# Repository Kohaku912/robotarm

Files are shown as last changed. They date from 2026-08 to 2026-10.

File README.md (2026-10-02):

# 6軸 カメラグリッパ・ロボットアーム（パラメトリック設計）

> **FreeCAD + Python による完全パラメトリックな 6 軸アーム。** 1 つのパラメータ表から
> CAD・STL・URDF・2D 図面を生成し、6 種類の自動検証（干渉・可到達範囲・印刷サイズ・
> 締結形状・サーボ駆動・自己干渉）をすべてパスさせています。







**English summary** — A fully parametric 6-DOF camera-gripper arm designed in FreeCAD from a
single parameter table, which then generates STL meshes, a URDF model, and 2D drawings.
An automated validation suite checks print-bed size, fastener features, forward-kinematics
reach, collision, servo drive torque, and self-collision — **6/6 passing**.

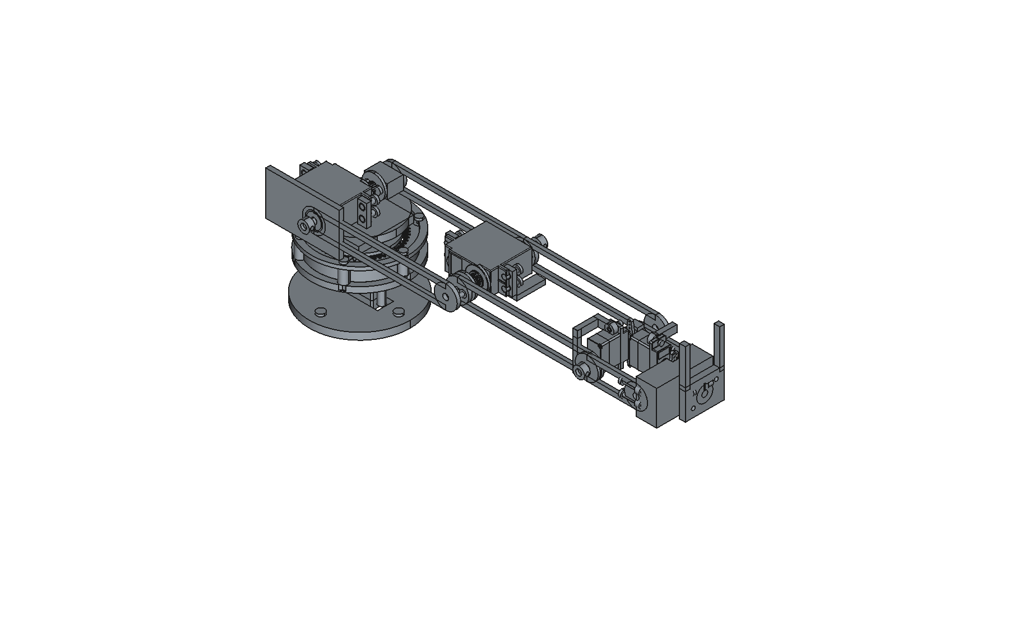
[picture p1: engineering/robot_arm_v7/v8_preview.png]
アーム外観


---

## 仕様

| 項目 | 値 |
|---|-----|
| 自由度 | 6 軸（J1 ヨー / J2 肩 / J3 肘 / J4 手首ピッチ / J5 ロール / J6 ヨー）+ グリッパ + カメラチルト |
| 到達距離（目安） | ~350 mm（上腕 140 + 前腕 120 + 手首 ~70） |
| ペイロード | 先端 100 g |
| サーボ | MG996R ×2（J1/J2）、MG90S ×6（J3–J6・グリッパ・カメラチルト） |
| 軸受 | F695ZZ ×5、F685ZZ ×5（フランジ軸受で径方向荷重を受ける） |
| 印刷制約 | 1 パーツ ≤180 mm（実測最大 129.92 mm） |
| 締結 | **接着禁止** — ねじ・圧入・軸嵌合のみ |

設計根拠は [`docs/design_notes.md`](docs/design_notes.md)、2D 図面は [`docs/2d/`](docs/2d/) を参照。

## 設計方針

実機（OmArm / Omartronics 系）のパターンに合わせ、
**サーボ片側＋対向フランジ軸受＋ホーン締結** を全関節で統一しています。

1. **固定側** — サーボポケット（公開寸法のタブ穴で位置決め）
2. **駆動側** — 円形ホーンをリンクにねじ止め
3. **反対側** — F695 / F685 フランジ軸受座 + Ø5 軸
4. ケーブル通し穴を確保し、分割リンクはダボ + M3 インサートで結合

サーボ出力軸に曲げモーメントを入れない構成にすることで、
MG90S のような小型サーボでも関節を成立させています。

---

## 生成物

`params.py` を唯一の真実源として、FreeCAD 経由で以下を再生成できます。

| 出力 | 内容 |
|---|---|
| `export/stl/` | 印刷用 STL **20 点**（ベース板〜フィンガ） |
| `export/fcstd/RobotArm.FCStd` | FreeCAD アセンブリ |
| `export/vendor/*.step` | サーボ／軸受／ホーンの参照モデル |
| `urdf/robot_arm.urdf` + `urdf/meshes/` | シミュレーション用 URDF |
| `docs/2d/*.svg` | 2D プロファイル **11 点** |

## 生成手順（FreeCAD）

FreeCAD の Python コンソールで、リポジトリの `generate_arm.py` を実行します。

```python
exec(open("generate_arm.py", encoding="utf-8").read())
```

> 絶対パスで実行する場合は、クローンしたディレクトリの `generate_arm.py` を指定してください。

SVG のみ再出力する場合:

```bash
python cad/export_svg.py
```

寸法変更は [`params.py`](params.py) を編集して再生成するだけです。

---

## 検証結果

```bash
py -3.11 tests/run_validation.py
```

結果は `export/validation_report.json` に出力されます。**全 6 項目パス**（`"ok": true`）。

| 検証項目 | 内容 | 結果 |
|---|---|---|
| `print_size` | 全 STL が印刷ベッド内（最大 129.92 mm） | ✅ |
| `fastener_features` | ねじ穴・インサート座の形状検証 | ✅ |
| `fk_reach` | 順運動学による到達距離 | ✅ |
| `collision` | パーツ間干渉チェック | ✅ |
| `servo_drive` | サーボ駆動トルクの余裕 | ✅ |
| `self_collision_flag` | 自己干渉の判定 | ✅ |

---

## 物理シミュレーション

### PyBullet（GUI 操作デモ）

Python **3.10–3.12** が必要です。

```bash
py -3.11 -m pip install pybullet
py -3.11 sim/pybullet_arm.py
```

または `sim/run_gui.bat`。スライダーで J1–J6・グリッパ・カメラチルトを動かすと、
重力下でアーム全体が追従します。ヘッドレス確認:

```bash
py -3.11 sim/pybullet_arm.py --direct
```

### numpy フォールバック

PyBullet が使えない環境向け。PD サーボ追従＋重力トルクの簡易物理:

```bash
py -3.11 -m pip install numpy matplotlib
py -3.11 sim/numpy_physics_arm.py
# または
py -3.11 sim/numpy_physics_arm.py --no-plot
```

---

## 組立順（概略）

1. ベース板＋カラムに MG996R と F695ZZ → タレット下面軸受・ホーン結合
2. タレット U 頬に F695ZZ ×2 → 肩 MG996R → ホーン／アイドラを上腕へ
3. 上腕分割結合 → 肘 MG90S + F695ZZ
4. 前腕 → 手首ピッチ／ロール／ヨー（F685ZZ）
5. グリッパ → カメラチルト（60×8 基板、Ø6 レンズ逃げ）

締結の詳細は [`bom.md`](bom.md) を参照。

---

## リポジトリ構成

```
params.py            # 寸法パラメータ（唯一の真実源）
generate_arm.py      # FreeCAD 生成スクリプト
cad/                 # 2D スケッチ・押し出し定義
sim/                 # PyBullet / numpy シミュレーション
tests/               # 自動検証スイート
urdf/                # URDF + メッシュ
export/              # 生成物（STL / FCStd / STEP / 検証レポート）
docs/                # 設計ノート・2D 図面
engineering/         # 設計検討の履歴（プレビュー画像を含む）
bom.md               # 部品表・締結仕様
```

## ライセンス

© 2026 Kohaku912. All rights reserved.

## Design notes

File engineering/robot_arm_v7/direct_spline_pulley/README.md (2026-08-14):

# MG996Rホーンレス直結16Tプーリー試作

支給された `MG996R_SERVO.step` の出力スプラインB-repを雌型として使用した、J2用3GT 16T・幅9 mmの試作部品。ホーンは使用せず、スプラインでトルクを伝え、中央M3ねじで軸方向を保持する。

## 重要

- 状態は `PROTOTYPE_NOT_LOAD_APPROVED`。主設計の支持入力軸とF685ZZ×2を省略するため、約120.7 Nのベルト接線力と張力がサーボ出力軸受へ戻る。
- クーポンの角欠き側が0.05 mm、中央が0.10 mm、反対端が0.15 mm。試験は反対端の0.15、中央0.10、角欠き側0.05 mmの順で、電源を切ったサーボへ手で試す。工具で押し込まない。
- 中央ねじはM3×8またはM3×10、頭径6 mm・高さ2 mmを想定。実サーボの中央雌ねじがM3であること、底付きしないことを実測する。
- 0.10 mm版を標準STLにした。緩い場合でも接着剤で補修せず、クリアランス値を変更して再生成する。

## 印刷条件

- Fiberon PA12-CF10、乾燥条件を材料仕様に従って記録
- 軸方向Z、0.15 mm層、8周、スプライン周囲100%相当
- 積層後にバリだけ除去し、スプライン歯面をドリルやリーマで加工しない

## 合格手順

1. クーポンが手圧で奥まで入り、逆さにして自然落下せず、抜去後にサーボ歯面を傷つけない。
2. 中央ねじを低トルクで締め、プーリー端面の振れを測る。
3. 無負荷で低速往復し、割れ、偏心、異音がない。
4. ベルトを掛ける前に30秒保持試験を行う。
5. ベルト試験では軸受温度、ガタ、歯飛びを確認する。合格するまでロボットアームへ採用しない。

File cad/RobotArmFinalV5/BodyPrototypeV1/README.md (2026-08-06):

# Robot Arm Body Prototype V1

5軸ロボットアーム本体の印刷データです。公差クーポンは含みません。

## 確定公差
- F695ZZ座: 13.05 mm
- M5密着穴: 5.00 mm
- M5通し穴: 5.30 mm
- J1歯車中心距離: 54.55 mm
- J4歯車中心距離: 19.35 mm

`BODY_PLATE_01.stl`から順に印刷できます。各部品は4 mm以上の外接間隔で完全に分離され、接続線・外周フレーム・クーポンはありません。

最初は無通電で全軸を手回しし、F695ZZ外輪押さえ、M5軸カラー、歯車噛み合いを確認してください。

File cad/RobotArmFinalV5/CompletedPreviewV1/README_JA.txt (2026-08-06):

Robot Arm Completed Preview V1

Printed body: BodyPrototypeV1 source geometry
MG90S: TowerPro official nominal 22.8 x 12.2 x 28.5 mm, 13.4 g
MG996R: TowerPro official nominal 40.7 x 19.7 x 42.9 mm, 55 g
F695ZZ: NSK 5 x 13 x 4 mm, flange 15 x 1 mm
Straight home pose. Minor clone/cap/label/cable variations may differ.

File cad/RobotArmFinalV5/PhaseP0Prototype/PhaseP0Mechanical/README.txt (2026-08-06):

V5.7-P0 mechanical package. J1 print plates use separated solids with no connector lines. Conservative envelopes are broad-phase only.

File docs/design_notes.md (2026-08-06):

# Realistic redesign notes — sources and mechanical rationale

## Reference projects

| Project | Reach | Payload | Actuators | Takeaway |
|---|---|---|---|---|
| OmArm Zero | ~303 mm | ~141 g | 3× MG996R + 3× SG90 | With only 2× MG996R, keep reach ~350 mm and short distal links |
| Omartronics 6-DOF | hobby | light | MG996R base/shoulder/elbow | Base servo + bearing under turret; U-yoke shoulder |
| Typical servo arm | — | — | horn + opposite bearing | Load path never through servo case alone |
| Thor | 625 mm | 750 g | steppers + belts | Structural inspiration only; not used (wrong actuators) |

## Joint pattern (applied to every revolute joint)

1. Servo body pocket with datasheet tab-hole spacing
2. Circular horn bolted to the driven link
3. Opposite cheek: flanged bearing seat + Ø5 shaft through bearing ID
4. Cable pass-through with rounded entry
5. Soft mechanical stops near ±90° (servo 180° class)

## Bearing allocation (stock exact)

- F695ZZ ×5: J1×2, J2×2, J3×1
- F685ZZ ×5: J4×2, J5×2, J6×1

## Link lengths (axis to axis)

- Upper arm: 140 mm (split 70+70 for 180 mm bed)
- Forearm: 120 mm (split 60+60)
- Wrist stack: ~70 mm
- Approx reach (J1 axis to wrist flange): ~350 mm

## Hardware dimensions (rebuilt from published specs, not copied CAD)

- MG996R: body ~40.7×19.7, tab length ~54.5, hole pitch ~49.5×10
- MG90S: body ~22.8×12.2×28.5, tab hole pitch ~28
- F695ZZ: 5×13×4, flange Ø15
- F685ZZ: 5×11×5, flange Ø12.5

## CAD method

1. Draw 2D profiles (`docs/2d/*.svg` + sketch point loops)
2. Extrude / pocket via `cad/sketch_pad.py` (Sketch→Pad equivalent)
3. Fit-check against `vendor/` solids
4. Export STL + URDF; drive with PyBullet position-controlled joints

## Torque note

MG996R ~10 kg·cm. Tip 100 g at 350 mm ≈ 3.5 kg·cm from payload alone; self-weight adds more.
Shoulder (J2) is the bottleneck. Elbow on MG90S requires the shorter forearm.

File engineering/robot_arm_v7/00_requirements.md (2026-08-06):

# ROBOT ARM V7 設計入力

状態: `PRE-CAD COMPLETE / CAD AUTHORIZED`

## 性能要求

| ID | 項目 | 設計値 |
|---|---|---:|
| REQ-01 | 先端ペイロード | 50 g |
| REQ-02 | 公称最大リーチ | 288 mm |
| REQ-03 | 水平保持 | 30 s、デューティ20% |
| REQ-04 | 最大関節速度 | 60 deg/s |
| REQ-05 | 最大関節加速度 | 120 deg/s^2 |
| REQ-06 | 急停止減速度 | 600 deg/s^2 |
| REQ-07 | サーボ電源 | 4.8 V nominal |
| REQ-08 | 構造安全率 | 2.0 |
| REQ-09 | 軸・ねじ安全率 | 2.0 |
| REQ-10 | 軸受静定格安全率 | 1.5 |
| REQ-11 | 接合方式 | ねじ、インサート、クランプ、軸、軸受、スプライン、圧入のみ |
| REQ-12 | 禁止 | 魔法の固定、CAD拘束だけの動力伝達、未定義接着、部品重なり |

## 材料・製造

| ID | 対象 | 指定 |
|---|---|---|
| MAT-01 | 構造部品 | Fiberon PA12-CF10、FDM、密度1.06 g/cm3 |
| MAT-02 | 遊星歯車 | PA12、FDM試作。20 degインボリュートへ更新必須 |
| MAT-03 | 軸 | 直径5 mm SUJ2相当精密シャフト |
| MAT-04 | ねじ・カラー | 鋼製市販品 |
| MAT-05 | FDM許容応力 | Z方向の湿潤引張強度42.1 MPaに対し、設計許容20 MPa |

## 未確定入力

| ID | 不足情報 | 完成判定への影響 |
|---|---|---|
| IN-01 | M3インサート | 解決: 熱圧入、外径6、全長4 mm、100個 |
| IN-02 | M4インサート | 解決: 熱圧入、外径5、全長3～8 mmを各30個 |
| IN-03 | 各ねじ長さごとの在庫数量 | 最終BOMの必要数量と現物を照合する |

ねじ数量の照合が終わるまで購入不足判定のみ`CONDITIONAL`とする。CAD設計は開始可能。

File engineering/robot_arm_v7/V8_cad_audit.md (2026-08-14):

# V8 automated CAD audit

Overall: **FAIL_NOT_COMPLETE**

Physical features: 157; arm mass excluding fixture inserts: 558.57 g.

| Check ID | Status | Evidence |
|---|---|---|
| AUD-MATERIAL-METADATA | PASS | 157 physical features covered |
| AUD-SHAPE-VALIDITY | PASS | 157 valid B-reps |
| AUD-UNCONNECTED | PASS | No physical feature lacks a ConnectionID |
| AUD-PRINTED-SINGLE-SOLID | PASS | 25 printed BOM parts are each one connected solid |
| AUD-NO-OVERLAP-AS-JOINT | PASS | No structural overlap is authorized merely by a shared ConnectionID; tolerance 0.05 mm3 |
| AUD-INVENTORY-F695 | PASS | {"installed": ["F695_J1_1", "F695_J1_2", "F695_J2_L", "F695_J2_R", "F695_J3", "F695_J4"], "owned": 5, "purchase_required": 1} |
| AUD-INVENTORY-F685 | PASS | {"installed": ["J1_PLANET_BRG_1", "J1_PLANET_BRG_2", "J1_PLANET_BRG_3", "F685_J5_A", "F685_J5_B", "F685_J2_INPUT_A", "F685_J2_INPUT_B"], "owned": 5, "purchase_required": 2} |
| AUD-INSERT-M3-SPEC | PASS | ["J1_CASE_1:OD6.0xL4.0", "J1_CASE_2:OD6.0xL4.0", "J1_CASE_3:OD6.0xL4.0", "J1_CASE_4:OD6.0xL4.0", "J1_CASE_5:OD6.0xL4.0", "J1_CASE_6:OD6.0xL4.0", "J1_OUTPUT_CLAMP:OD6.0xL4.0", "J2_SHAFT_CLAMP_L:OD6.0xL4.0", "J2_SHAFT_CLAMP_R:OD6.0xL4.0", "UA_SPACER_1_L:OD6.0xL4.0", "UA_SPACER_1_R:OD6.0xL4.0", "UA_SPACER_2_L:OD6.0xL4.0", "UA_SPACER_2_R:OD6.0xL4.0", "J5_HOUSING_INS_1_1:OD6.0xL4.0", "J5_HOUSING_INS_1_2:OD6.0xL4.0", "J5_HOUSING_INS_2_1:OD6.0xL4.0", "J5_HOUSING_INS_2_2:OD6.0xL4.0", "J5_TOOL_CLAMP:OD6.0xL4.0", "J2_BRIDGE_INS_1:OD6.0xL4.0", "J2_BRIDGE_INS_2:OD6.0xL4.0", "J2_BRIDGE_INS_3:OD6.0xL4.0", "J2_BRIDGE_INS_4:OD6.0xL4.0", "J4_HORN_1:OD6.0xL4.0", "J4_HORN_2:OD6.0xL4.0"] |
| AUD-INSERT-M4-SPEC | PASS | ["BASE_M4_1:OD5.0xL6.0", "BASE_M4_2:OD5.0xL6.0", "BASE_M4_3:OD5.0xL6.0", "BASE_M4_4:OD5.0xL6.0", "J2_SERVO_1_1:OD5.0xL4.0", "J2_SERVO_1_2:OD5.0xL4.0", "J2_SERVO_2_1:OD5.0xL4.0", "J2_SERVO_2_2:OD5.0xL4.0", "J3_SERVO_1_1:OD5.0xL4.0", "J3_SERVO_1_2:OD5.0xL4.0", "J3_SERVO_2_1:OD5.0xL4.0", "J3_SERVO_2_2:OD5.0xL4.0"] |
| AUD-FASTENER-LENGTH-ENGAGEMENT | PASS | 49 screws within inventory/purchase ranges |
| AUD-TOOL-ACCESS | PASS | 49 screws define direction, >=8 mm clearance, and assembly stage |
| AUD-SERVO-STEP-HOLE-AXIS | PASS | 14 servo fastener axes match STEP hole/slot centers within 0.05 mm |
| AUD-PHYSICAL-CONNECTION-GRAPH | FAIL | ["C-J2-HORN-COUPLER:J2_SERVO_HORN", "C-J2-HORN-COUPLER:J2_HORN_SHAFT_COUPLER", "C-J3-ACTIVE:J3_SERVO_HORN", "C-J3-ACTIVE:J3_HORN_M3_1", "C-J3-ACTIVE:J3_HORN_1"] |
| AUD-NO-MAGIC-FIXED-JOINTS | PASS | No FreeCAD constraint is credited as hardware |
| AUD-INTEGRAL-SERVO-MOUNTS | PASS | J1-J5 cradle features are fused into one-solid structural hosts; no separate mount BOM items |
| AUD-SERVO-HOST-NO-VOLUME-OVERLAP | PASS | All purchased servo cases have zero common volume with their printed hosts; seating is by ear faces |
| AUD-EXACT-SERVO-HORN-GEOMETRY | FAIL | ["J2_SERVO_HORN", "J3_SERVO_HORN"] |
| AUD-EXACT-SERVO-BODY-GEOMETRY | PASS | All five servo bodies trace to supplied STEP files |
| AUD-PURCHASED-SERVO-UNMODIFIED | PASS | Placed servo B-rep volumes equal source volumes within 0.01 mm3 |
| AUD-PITCH-LOAD-CASES-SF | PASS | [{"joint": "J2", "stall_Nm": 1.6596, "load_cases": {"static": {"demand_Nm": 0.517907, "sf": 3.2044}, "max_accel_120_deg_s2": {"demand_Nm": 0.544641, "sf": 3.0471}, "emergency_stop_600_deg_s2": {"demand_Nm": 0.65158, "sf": 2.547}}}, {"joint": "J3", "stall_Nm": 0.922, "load_cases": {"static": {"demand_Nm": 0.247761, "sf": 3.7213}, "max_accel_120_deg_s2": {"demand_Nm": 0.256204, "sf": 3.5987}, "emergency_stop_600_deg_s2": {"demand_Nm": 0.289976, "sf": 3.1796}}}, {"joint": "J4", "stall_Nm": 0.177, "load_cases": {"static": {"demand_Nm": 0.068699, "sf": 2.5765}, "max_accel_120_deg_s2": {"demand_Nm": 0.069538, "sf": 2.5454}, "emergency_stop_600_deg_s2": {"demand_Nm": 0.072896, "sf": 2.4281}}}] |
| AUD-J2-PHYSICAL-2TO1-BELT | PASS | {"part": "BELT-J2-135-3GT-90", "ratio": 2.0, "efficiency": 0.9, "pitch_mm": 3.0, "width_mm": 9.0, "length_mm": 135.0, "wrap_deg": 151.0323, "engaged_teeth": 6.7125} |
| AUD-MUJOCO-TRANSMISSION-MATCH | PASS | {"motor": "J2_MG996R_16T_32T_3GT", "gear_Nm": 1.6596, "ratio": "2.0", "efficiency": "0.90", "transmission_id": "P-J2-BELT"} |
| AUD-BELT-CAPACITY-PHYSICAL-COUPON | FAIL | 3GT printed-tooth coupon and MISUMI capacity confirmation are required before manufacture approval |
| AUD-PHYSICAL-VALIDATION | FAIL | Pending insert pull-out, bearing press-fit, 30 s hold, and 600 deg/s2 emergency-stop tests |
| AUD-MOTION-SWEEP-CURRENT | FAIL | MuJoCo sweep must be rerun after exact-servo geometry and J5 axis relocation; local mujoco module unavailable |

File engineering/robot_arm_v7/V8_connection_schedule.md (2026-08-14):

# V8 結合・動力・荷重経路

## 結合グラフ

`外部治具 → B0_BASE → J1遊星/軸受/割締め → B1_TURNTABLE → J2 3GT減速/固定肩軸 → B2_UPPER_ARM → J3 → B3_FOREARM → J4 → B4_WRIST_PITCH → J5 → B5_TOOL`

| Connection ID | 実物の結合 | 穴・ねじ・保持 | 工具アクセス |
|---|---|---|---|
| C-J1-SERVO | MG90S実耳→基台一体ボス | 実穴2.4、M2×8×2、M2 OD3.5×L3、ねじ込み3 | +Z、ケース閉鎖前 |
| C-J2-SERVO | MG996R実スロット→ターンテーブル一体座 | 実スロット4.44、M4×12×4、M4 OD5×L4 | +Y、上腕取付前 |
| C-J2-HORN-COUPLER | 実MG996Rホーン→印刷フランジ→5 mm入力軸割締め | 純正中央ねじ、実測穴M3、M3 OD6×L4 | ホーン実測後に確定。未成立のため監査FAIL |
| C-J2-INPUT-SUPPORT | 入力軸→F685ZZ×2→スライド支持橋→ターンテーブル | 10.96 mm圧入座、M3×12×4、±1 mm調整 | +Z、ベルト装着前 |
| C-J2-BELT | 16T→GBN1353GT-90→上腕右板一体32T | 3GT、幅9、周長135、中心距離30.545 | 外側Y、ガード閉鎖前 |
| C-J2-OUTPUT-BEARINGS | 上腕左右板F695ZZ×2→固定5 mm肩軸 | 左右反向きフランジ、軸102 mm | 上腕組立時 |
| C-J2-RETENTION | 固定肩軸→ターンテーブル左右割締め | M3×17×2、M3 OD6×L4、軸平面0.5 | ±X、上腕取付前 |
| C-UA-CROSS | 上腕左右板→印刷クロススペーサ×2 | 各端M3×9、M3 OD6×L4 | ±Y、J3取付前 |
| C-J3-SERVO | MG996R実スロット→上腕右板一体座 | M4×11×4、M4 OD5×L4 | +Y、前腕取付前 |
| C-J4-SERVO | MG90S実穴→前腕左板一体座 | M2×8×2、M2 OD3.5×L3 | +Y、手首取付前 |
| C-J5-SERVO | MG90S実穴→手首右板一体座 | M2×8×2、M2 OD3.5×L3 | +X、ハウジング閉鎖前 |

J1/J4/J5の既存ホーン締結、J1ケース、J3/J4受動軸、J5二軸受ハウジングは従来の実ねじ・軸受・カラー方式を維持する。M3通し穴3.4、M4通し穴4.5、M2通し穴2.2 mm。低頭寸法はM3頭Ø6×H2、M4頭Ø7×H2。熱圧入下穴は材料クーポンで決定する。

## 動力伝達

- `P-J1`: MG90S→実ホーン→12/24/60T遊星6:1→5 mm軸→ターンテーブル。
- `P-J2-BELT`: MG996R→実ホーン→M3フランジ→5 mm支持入力軸→16T→3GTベルト→上腕一体32T。`q_servo=2q_J2`、`τ_J2=2×0.90×τ_servo`。
- `P-J3`: MG996R→実ホーン→M3締結→前腕。ホーン実測待ち。
- `P-J4/J5`: MG90S実ホーンと物理アダプタによる直結。

## 荷重・反力経路

50 g荷重→工具→J5 F685対→手首→J4軸受/ホーン→前腕→J3軸受/ホーン→上腕一体32TおよびF695対→固定肩軸→左右割締めターンテーブル→J1 F695対→ギアケース→基台M4×4→外部治具。J2ベルト反力は16T→5 mm入力軸→F685対→M3×4支持橋→ターンテーブルへ戻り、MG996R出力軸へラジアル荷重を負担させない。

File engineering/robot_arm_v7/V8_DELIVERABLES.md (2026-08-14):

# ROBOT ARM V8 成果物索引

- FreeCAD: `C:/Users/kohak/programs/robotarm/cad/RobotArmFinalV5/CompletedPreviewV5_2CradleAlignment/ROBOT_ARM_V8_MANUFACTURABLE.FCStd`
- 1行1部品BOM: `V8_BOM.csv`
- 在庫・購入表: `V8_purchase_and_inventory.md`
- 結合/動力/荷重経路: `V8_connection_schedule.md`
- 計算: `V8_final_calculations.md`
- 組立: `V8_assembly_sequence.md`
- サーボSTEP反映記録: `V8_servo_source_data.md`
- MuJoCo: `robot_arm_v8.xml`, `V8_mujoco_validation.md`
- FreeCAD監査: `V8_cad_audit.json`, `V8_cad_audit.md`
- TechDraw: `V8_TechDraw_Assembly.pdf`, `V8_TechDraw_J1.pdf`, `V8_TechDraw_Links.pdf`, `V8_TechDraw_J2_Belt.pdf`
- MG996Rホーン測定入力: `mg996_horn_measurements.json`
- 未解決リスク: `V8_unresolved_risks.md`

設計状態: `FAIL_NOT_COMPLETE / EXACT MG996R HORN, BELT COUPON, CURRENT MUJOCO SWEEP, AND PHYSICAL VALIDATION PENDING`。J2 2:1急停止計算は合格済みだが、未実測項目が残るため完成とは宣言しない。

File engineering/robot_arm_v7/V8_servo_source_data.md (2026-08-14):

# サーボCADデータ反映状況

## 取り込んだユーザーデータ

| ファイル | SHA/保存先 | 使用内容 |
|---|---|---|
| MG90s_Horn.step | `vendor/servo_cad/MG90S_HORN.step` | 36×8×5 mmのダブルアームホーン。J1/J4/J5に使用 |
| MG90S Micro Servo Motor.step | `vendor/servo_cad/MG90S_SERVO.step` | 中央保持ねじ形状とホーン組付け基準 |
| Servo MG996R.STEP | `vendor/servo_cad/MG996R_SERVO.step` | MG996R筐体・出力スプライン参照。ホーンは含まれない |

SHA-256: MG90S horn `8C428DD318A7E22E306891E47F606A9B6688F3669DC7F9C54D71B26543957D99`; MG90S servo `655BE9FACE0FC062FCAF81FB7811722D9DA1611A2E4B36BA4494F5C3845A1293`; MG996R servo `6FABFCE4C057604B33F8E49768FB1886B1E99FB4CBFA6001B8DBA6BCD5FC6E18`.

MG90S実ホーンの取付穴列は中心から左右6.5、9.0、11.5、14.0、16.5 mm。V8では最内側の±6.5 mmを使用する。J1はM2×7とM2 OD3.5×L3熱圧入インサート、J4はM3×15とM3 OD6×L4インサート、J5はM2×5とロックナットで締結する。すべてにサーボ付属中央保持ねじを独立部品として追加した。

J1ではホーンを37.5°回して惑星歯車と締結部品を離した。J4/J5ではホーン腕を縦向きにし、隣接サーボ・側板との干渉を回避した。J5ハウジングには実ホーン腕用スロットを追加した。

MG996Rデータは単一ソリッドでホーンを含まない。このためJ2/J3のホーンと受け座は最終形状ではなく、監査 `AUD-EXACT-SERVO-HORN-GEOMETRY` を意図的にFAILとする。

## サーボ本体の実STEP置換（2026-08-06）

- J1/J4/J5の本体は `MG90S_SERVO.step` の筐体＋出力軸ソリッドを無加工で配置した。出力基準はローカル `(0,0,0)`、軸はローカルZ。取付穴は直径2.4 mm、ローカルX=`-8.55, 19.15 mm`、穴厚2.4 mm。
- J2/J3の本体は `MG996R_SERVO.step` の単一ソリッドを無加工で配置した。出力基準はローカル `(10,47.6,-10) mm`、軸はローカルY。取付スロットは直径4.44 mm、X=`-5.0,45.3 mm`、Z=`-5.5,-14.5 mm`。
- `AUD-EXACT-SERVO-BODY-GEOMETRY` は5台すべてのSTEP出典を検査し、`AUD-PURCHASED-SERVO-UNMODIFIED` は配置後B-rep体積と元STEP体積を0.01 mm³以内で比較する。両方PASS。
- J2/J3は実スロットへM4低頭ねじ4本とM4 OD5×L4熱圧入インサートで固定する。J1/J4/J5は実2.4 mm穴へM2×8ねじとM2 OD3.5×L3インサートで固定する。購入サーボには切削、穴拡大、ボス追加を行わない。
- 実MG90S同士が旧J4–J5軸間30 mmで1,169.037 mm³干渉したため、J5軸をX=273 mmへ13 mm移動した。現在のケース間最小X余裕は約4.7 mm。

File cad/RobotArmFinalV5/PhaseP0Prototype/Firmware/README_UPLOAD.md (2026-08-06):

# UNO R4 WiFi commissioning package

Detected board:

- Board: Arduino UNO R4 WiFi
- Normal port: COM3
- FQBN: `arduino:renesas_uno:unor4wifi`
- Board core: 1.5.3

Installed on the user's PC:

- ArduinoJson 7.4.2
- Servo library

Both the safe commissioning sketch and full P0 sketch compiled successfully.

## Current blocker

Windows lists COM3, but opening it returns:

`A device attached to the system is not functioning.`

The current board sketch appears to expose a broken CDC serial endpoint.
The physical RESET button must be double-pressed so the bootloader creates a
temporary usable serial port.

## Safe upload

External servo power should remain disconnected.

```powershell
cd "$HOME\Documents\RobotArmFinalV5\PhaseP0Prototype\Firmware"
.\upload_safe_commissioning.ps1
```

When prompted, double-press RESET. The script automatically detects the
temporary bootloader COM port and uploads the safe diagnostic firmware.

The diagnostic firmware:

- does not attach any Servo object;
- keeps D13 LOW;
- never enables servo power;
- reports the six NC inputs;
- reports E-stop state;
- reports provisional A0/A1 current and voltage readings.

## Full PWM upload

Only after the diagnostic inputs are verified:

```powershell
.\upload_full_p0.ps1 -ServoPowerPhysicallyDisconnected
```

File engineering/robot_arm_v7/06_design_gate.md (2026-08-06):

# CAD開始ゲート

| ゲート | 状態 |
|---|---|
| 部品一覧 | PASS |
| 物理結合グラフ | PASS-CONDITIONAL |
| 動力伝達グラフ | PASS |
| 荷重経路 | PASS |
| 主要計算 | PASS-CONDITIONAL |
| 購入部品一覧 | PASS-CONDITIONAL |
| インサート長・形状 | PASS |
| ねじ・インサート数量 | PASS-CONDITIONAL / ねじ在庫照合待ち |

CAD形状作成を許可する。最終BOMのねじ必要数量を提示し、在庫不足があれば購入品へ移す。

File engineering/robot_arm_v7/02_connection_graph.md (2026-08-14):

# 物理結合グラフ

各辺は実在する結合要素を持つ。FreeCAD拘束だけの辺は禁止する。

| 接続ID | 部品A | 部品B | 結合方法 | 数量・主要寸法 | 解除工具 |
|---|---|---|---|---|---|
| C-B01 | PR-B01 | 作業台 | M4低頭ねじ＋M4インサート/ナット | 4、穴4.5、Lは台厚依存 | 六角レンチ |
| C-J1-01 | SER-J1 | PR-B01 | M3低頭ねじ＋INS-M3 | 4、穴3.4、M3インサート長4、ねじ込み4.0 | 六角レンチ |
| C-J1-02 | SER-J1スプライン | 付属ホーン | 純正スプライン＋中央ねじ | 1、純正ねじ | ドライバー |
| C-J1-03 | 付属ホーン | PR-G03 | M3ねじ＋INS-M3 | 4、PCD実測、M3インサート長4 | 六角レンチ |
| C-J1-04 | PR-G04..06 | BR-685-1..3 | 圧入 | 穴10.96～10.98、外輪しめしろ0.02～0.04 | 圧入治具 |
| C-J1-05 | BR-685-1..3 | 5 mmプラネット軸 | すきまばめ | 軸g6、内輪回転 | 手組み |
| C-J1-06 | プラネット軸 | PR-G08/09 | M3ねじ締結キャリアで軸方向保持 | 各軸上下、計6 | 六角レンチ |
| C-J1-07 | PR-G07 | PR-G01/02 | M3ねじ＋INS-M3 | 6、穴3.4、M3インサート長4 | 六角レンチ |
| C-J1-08 | J1出力軸 | BR-695-1..2 | 軸g6すきま/中間ばめ | 5 mm | 圧入治具 |
| C-J1-09 | BR-695-1..2 | PR-G01/ターンテーブル | 外輪圧入＋フランジ肩 | 穴12.96～12.98、肩径15.2 | 圧入治具 |
| C-J1-10 | キャリア | J1出力軸 | 分割クランプ＋M3ねじ | クランプ穴4.9、M3×12 | 六角レンチ |
| C-J1-11 | J1出力軸 | ターンテーブル | 分割クランプ＋M3ねじ | M3×12 | 六角レンチ |
| C-J2-01 | SER-J2 | ターンテーブル一体耳座 | M4×12＋INS-M4 | 4、実スロット4.44、M4 OD5×L4 | 六角レンチ |
| C-J2-02 | SER-J2スプライン | 純正ホーン | 純正スプライン＋中央ねじ | 1 | ドライバー |
| C-J2-03 | 純正ホーン | 5 mm支持入力軸 | 実測穴M3＋印刷フランジ＋割締め | ホーン測定ゲート未完 | 六角レンチ |
| C-J2-04 | 5 mm入力軸 | F685ZZ×2/16T | 両側軸受＋プーリー割締め | 軸40 mm | 圧入治具・六角レンチ |
| C-J2-05 | 16T | 上腕一体32T | GBN1353GT-90 | 3GT×9、135 mm、2:1 | 張力治具 |
| C-J2-06 | 上腕左右板 | F695ZZ×2/固定肩軸 | 反向きフランジ＋左右割締め | 軸102 mm、M3×17×2 | 六角レンチ |
| C-J3-* | J3関連 | MG996R直結 | 実ホーン＋M3、受動F695 | ホーン測定ゲート未完 | 同左 |
| C-J4-* | J4関連 | J2と同型、MG90S寸法 | ねじ＋ホーン＋F695ZZ-5 | M3 | 同左 |
| C-J5-01 | SER-J5 | PR-W02 | M3ねじ＋INS-M3 | 4 | 六角レンチ |
| C-J5-02 | SER-J5 | J5軸 | 純正スプラインホーン＋分割クランプ | 中央ねじ＋M3×12 | 六角レンチ |
| C-J5-03 | J5軸 | BR-685-4..5 | 5 mm軸 | 軸受間隔20以上 | 手組み |
| C-J5-04 | BR-685-4..5 | PR-W03 | 圧入＋肩＋ねじ式リテーナ | 穴10.96～10.98、M3×8×3 | 六角レンチ |

純正ホーン穴PCDはCAD内の実形状から取得し、製造図で寸法化する。熱圧入下穴径は材料別クーポン試験を製造ゲートとする。

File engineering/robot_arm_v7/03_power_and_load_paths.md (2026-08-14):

# 動力伝達グラフ・荷重経路

## 動力伝達

| 経路ID | 入力から出力まで |
|---|---|
| P-J1 | MG90Sモータ → サーボ内歯車 → 出力スプライン → 純正ホーン → M3締結サンギア → 12/60/24遊星 → キャリア → 分割クランプ → 5 mm軸 → ターンテーブル |
| P-J2-BELT | MG996Rモータ → 内歯車 → 実ホーン → M3フランジ → 5 mm支持入力軸 → 16T → GBN1353GT-90 → 上腕一体32T。2:1、効率0.90 |
| P-J3 | MG996Rモータ → サーボ内歯車 → 出力スプライン → 純正ホーン → M3×4 → 前腕駆動板 |
| P-J4 | MG90Sモータ → 出力スプライン → 純正ホーン → M3×4 → 手首ピッチ部 |
| P-J5 | MG90Sモータ → 出力スプライン → 純正ホーン → 分割クランプ → 5 mm軸 → 手首ロール出力 |

## 反力・荷重経路

| 経路ID | 負荷からベースまで |
|---|---|
| L-GRAV | ペイロード → グリッパー → J5軸受対 → J4軸/F695 → 前腕 → J3ホーン/F695 → 上腕一体32T/F695対 → 固定肩軸/左右割締め → ターンテーブル → J1 F695対 → ギアケース → ベースM4×4 → 作業台 |
| L-J2R | ベルト張力 → 16T → 5 mm入力軸 → F685対 → M3×4支持橋 → ターンテーブル。サーボ出力軸へラジアル荷重を戻さない |
| L-J1R | J1リングギア反力 → M3×6 → ギアケース → ベースプレート → M4×4 → 作業台 |
| L-STOP | 先端慣性 → 各リンク曲げ/ねじり → 軸 → 内輪 → 転動体 → 外輪 → 圧入肩 → 構造板 → ベース |

## 軸方向保持

- J1: F695フランジ肩＋上下分割カラー。キャリアとターンテーブルは独立クランプ。
- J2: 上腕側F695を左右反向きに配置し、102 mm固定肩軸をターンテーブル左右割締めで保持。
- J3/J4: サーボホーン側をねじで保持し、反対側はF695フランジ＋5 mm分割カラー。
- J5: F685を2個離して配置し、両外側カラーとねじ式リテーナで抜け止め。
- プラネット: F685内輪を5 mm軸肩で支持し、上下キャリアとねじで軸方向保持。

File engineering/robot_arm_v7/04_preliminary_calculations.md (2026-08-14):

# 主要計算（CAD前）

> V8 J2改訂: 直結案は廃止し、16T/32T・3GT×9・135 mm・効率0.90の2:1ベルトを採用した。出力停止トルクは`0.922×2×0.90=1.6596 N m`。小プーリー巻付151.032°、噛合6.713歯、停止時接線力120.69 N。最終質量による再計算は`V8_final_calculations.md`を正とする。

## 公式部品値

- MG996R: 4.8 V停止トルク9.4 kgf cm = 0.922 N m、質量55 g。
- MG90S: 4.8 V停止トルク1.8 kgf cm = 0.177 N m、質量13.4 g。
- F695ZZ: Cr=1190 N、C0r=430 N、5x13x4 mm、フランジ15x1 mm。
- PA12-CF10: 密度1.06 g/cm3、湿潤Z引張強度42.1 MPa。設計許容20 MPa。

## LC-01 水平静荷重

肩軸まわりの暫定質量モデルから、構造・サーボ・締結品の重力モーメントを0.258 N m、50 gペイロードを0.141 N mと見積もる。

`T_J2_static = 0.258 + 0.050 * 9.80665 * 0.288 = 0.399 N m`

MG996R停止トルクに対する余裕率は`0.922 / 0.399 = 2.31`。

## LC-02 最大加速度120 deg/s2

肩軸まわり暫定慣性`I = 0.0090 kg m2`、`alpha = 2.094 rad/s2`。

`T_inertia = I * alpha = 0.019 N m`

`T_J2_accel = 0.399 + 0.019 = 0.418 N m`、停止トルク比45.3%。

## LC-03 急停止600 deg/s2

`alpha_stop = 10.472 rad/s2`

`T_stop = 0.399 + 0.0090 * 10.472 = 0.493 N m`

停止トルク安全率`0.922 / 0.493 = 1.87`。暫定サーボ基準1.5には合格するが、熱連続定格が公開されていないため、30秒保持温度試験を必須とする。

## J3概算

前腕以遠の重力トルク約0.172 N m。急停止を含めても0.23 N m未満の見込みで、MG996R停止トルク安全率は4以上。

## 5 mm鋼軸

J2最大トルク0.493 N mを中実丸軸へ入力したとき、

`tau = 16T / (pi*d^3) = 20.1 MPa`

SUJ2相当材の保守的許容せん断145 MPaに対し安全率7.2。最終CADの軸受間隔で曲げ合成応力を再計算する。

## 軸受

全遠位質量を0.25 kg、急停止等価3gとしても荷重は7.4 N。F695ZZ静定格430 Nに対し安全率58で、要求1.5を上回る。実際はモーメントを軸受間隔で受けるため、最終反力をCAD寸法から再計算する。

## 現時点の判定

| 検査 | 状態 | 理由 |
|---|---|---|
| 肩サーボ静荷重 | PASS-CONDITIONAL | 停止トルクSF2.31 |
| 肩サーボ急停止 | PASS-CONDITIONAL | SF1.87、熱定格不明 |
| J3サーボ | PRELIMINARY PASS | 最終質量待ち |
| 5 mm軸ねじり | PRELIMINARY PASS | SF7.2 |
| F695ZZ/F685ZZ | PRELIMINARY PASS | 最終反力待ち |
| PA12-CF構造 | NOT TESTED | 最終断面と印刷方向待ち |
| 遊星歯元 | NOT TESTED | インボリュート歯形と印刷条件待ち |

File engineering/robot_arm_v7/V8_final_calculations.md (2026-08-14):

# V8 最終設計計算

## 入力・CAD質量

- 4.8 V、50 gペイロード、到達301 mm、最大加速度120 deg/s²、急停止600 deg/s²。
- MG996R 0.922 N·m、MG90S 0.177 N·m。
- CAD質量558.568 g（外部治具インサート1.442 gを除く）。

| BodyID | 質量 g | CAD重心 mm (X,Y,Z) |
|---|---:|---|
| B0_BASE | 106.813 | 0.580, 0.000, 24.348 |
| B1_TURNTABLE | 237.298 | 19.502, 3.291, 68.817 |
| B2_UPPER_ARM | 97.406 | 85.582, 3.172, 81.909 |
| B3_FOREARM | 31.415 | 199.706, -1.301, 81.555 |
| B4_WRIST_PITCH | 69.627 | 265.341, -7.261, 80.114 |
| B5_TOOL | 16.010 | 292.127, -0.068, 81.899 |

## 静荷重・加速・急停止

CAD重心集中モデルで`T=Σmgr+Iα`を再計算した。各欄は需要トルク N·m / 安全率。

| 軸 | 実伝達の最大出力 N·m | 静荷重 | 120 deg/s² | 600 deg/s²急停止 |
|---|---:|---:|---:|---:|
| J2 MG996R＋2:1 3GT、効率0.90 | 1.6596 | 0.517907 / 3.204 | 0.544642 / 3.047 | 0.651580 / 2.547 |
| J3 MG996R直結 | 0.922 | 0.247761 / 3.721 | 0.256204 / 3.599 | 0.289976 / 3.180 |
| J4 MG90S直結 | 0.177 | 0.068699 / 2.576 | 0.069538 / 2.545 | 0.072896 / 2.428 |

## J2ベルト・軸・軸受

- 16T/32T、ピッチ径15.279/30.558 mm、中心距離30.545 mm、周長135 mm。
- 小プーリー巻付151.032°、噛合6.713歯、停止時接線力`0.922/(15.279/2)=120.69 N`。
- 仮の取付張力15 N/側では軸ラジアル荷重を約150.7 Nとする。
- 入力F685対は中央荷重として約75.4 N/個。C0=281 Nに対しSF=3.73。
- 入力軸の最大曲げ527 Nmm、曲げ42.9 MPa、ねじり37.6 MPa、合成78.2 MPa。許容300 MPa以上の硬化軸を購買条件としSF=3.84。
- 出力プーリー中心は右F695中心から約10.5 mm外側。右反力約173 N、F695 C0=430 Nに対しSF=2.48。固定5 mm軸の曲げは約129 MPaで、許容300 MPaに対しSF=2.33。

## ねじ・印刷支持橋

- MG996R四穴群の停止トルク反力は最大ねじ約10.85 N。M4軸せん断およびM4 OD5×L4インサート面圧は十分小さいが、耳の割れを含めクーポン締付試験を必須とする。
- J2支持橋M3×4は150.7 Nを等分して37.7 N/本、M3平均せん断5.33 MPa。A2-70保守許容135 MPaに対しSF=25.3。
- 支持橋の二本の最小4×8 mm相当梁で`M=FL/4=527 Nmm`、応力集中2を含む曲げ約12.4 MPa。PA12-CF10設計許容20 MPaに対しSF=1.61。
- 上腕・前腕は従来の二枚梁計算で応力集中込み5.2 MPa以下、設計許容20 MPaに対しSF>3.8。

## 判定

CAD質量による静荷重・600 deg/s²急停止、軸、軸受、ねじ、支持橋はSF≥1.5。MG996Rホーン実測、3GT歯形/容量クーポン、インサート引抜き、圧入、30秒保持、急停止実機試験、MuJoCo走査が未完のため製造承認ではない。

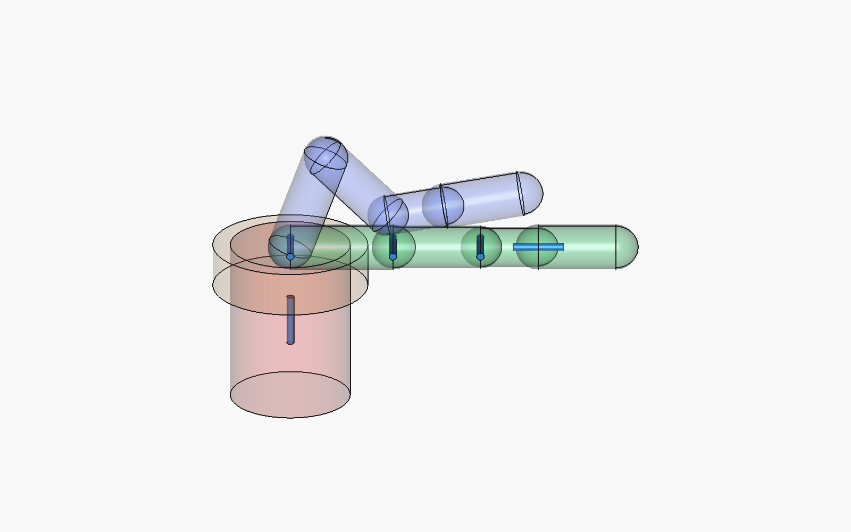
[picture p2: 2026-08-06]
cad/RobotArmFinalV5/PhaseP0Prototype/PhaseP0Mechanical/IMAGES/FULL_ARM_ENVELOPES.png

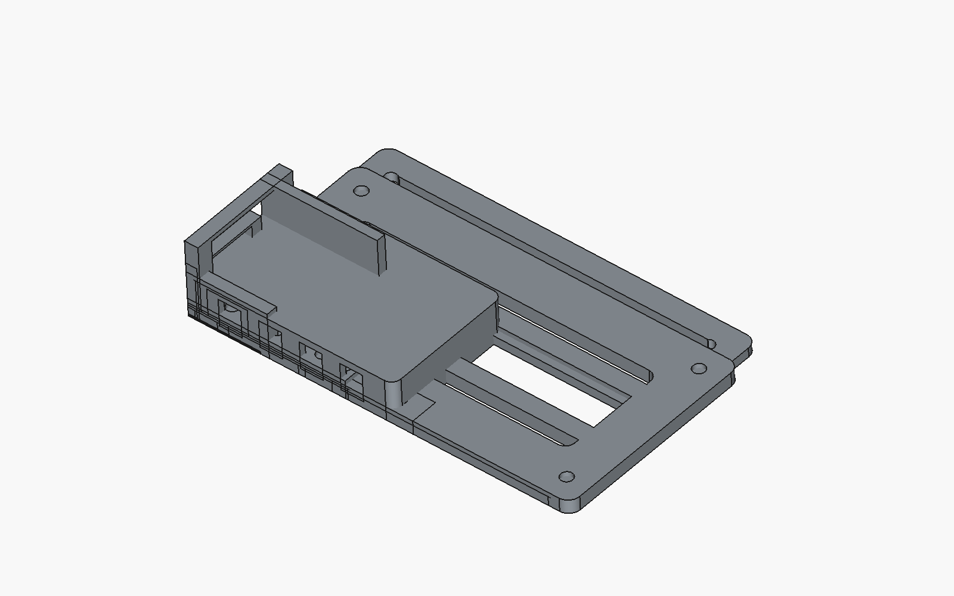
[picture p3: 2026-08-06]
cad/RobotArmFinalV5/PhaseP0Prototype/PhaseP0Mechanical/IMAGES/J1_EXPLODED_REFERENCE.png

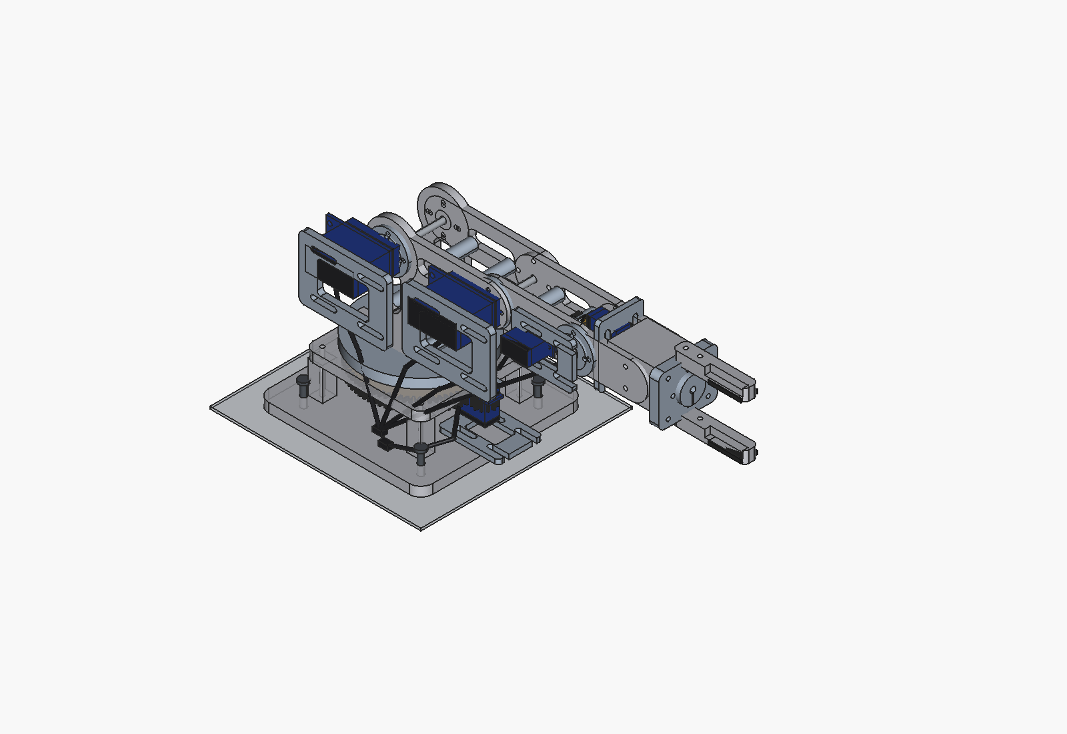
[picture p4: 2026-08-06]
cad/RobotArmFinalV5/CompletedPreviewV1/ROBOT_ARM_COMPLETED_PREVIEW_V1_AXON.png

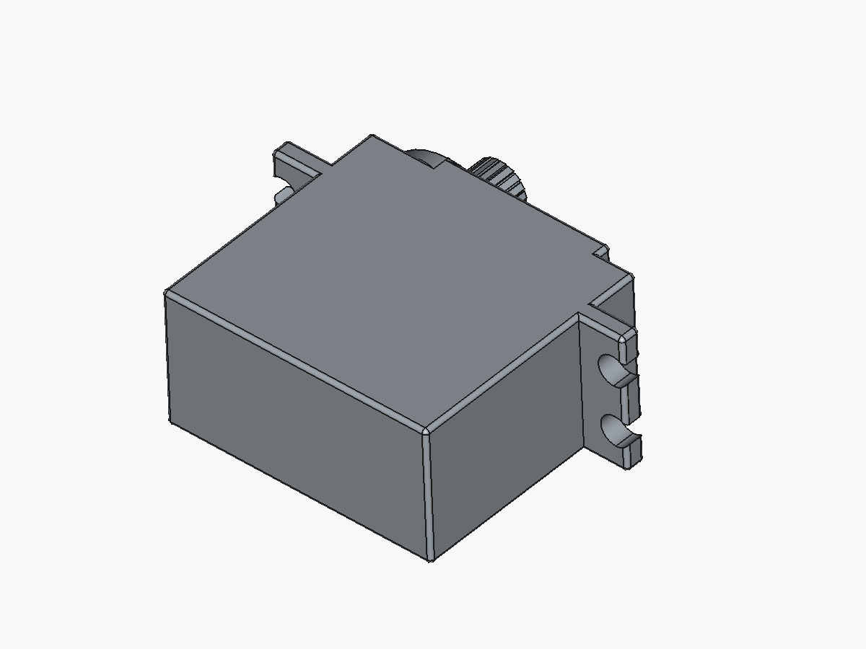
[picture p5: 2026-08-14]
engineering/robot_arm_v7/source_mg996_servo.png

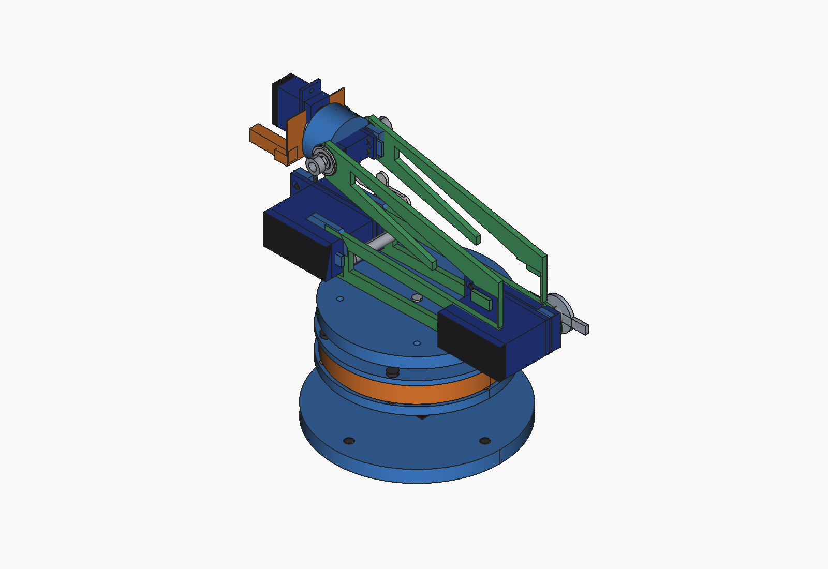
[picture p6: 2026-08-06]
engineering/robot_arm_v7/v7_preview.png

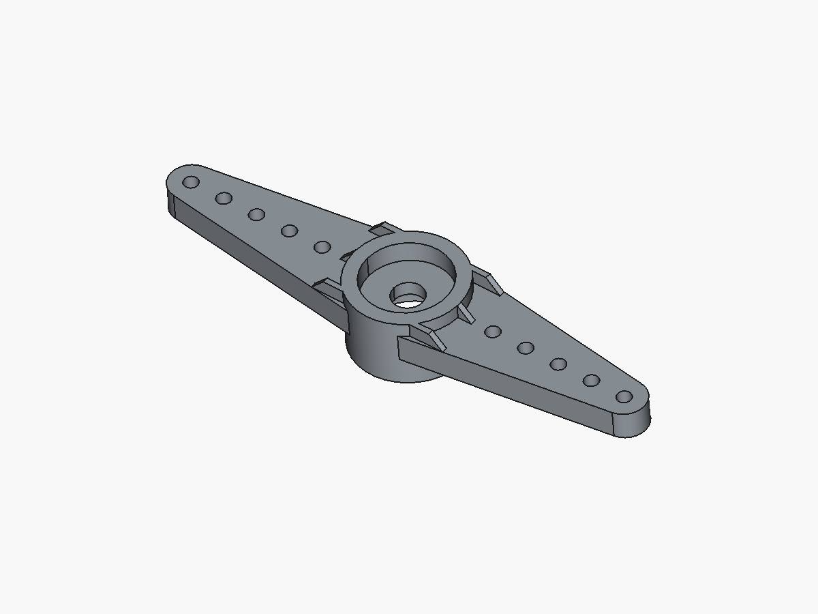
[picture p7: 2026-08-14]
engineering/robot_arm_v7/source_mg90_horn.png

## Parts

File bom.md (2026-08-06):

# BOM（現実的締結 — 接着禁止）

**接着は使わない。** 固定はねじ・ヒートセットインサート・軸受圧入・Ø5軸嵌合・ホーンねじのみ。

## アクチュエータ

| 部品 | 数量 | 箇所 |
|---|---|---|
| MG996R | 2 | J1 ベース、J2 肩 |
| MG90S | 6 | J3 肘、J4 ピッチ、J5 ロール、J6 ヨー、グリッパ、カメラチルト |

## 軸受（圧入）

| 部品 | 数量 | 嵌合 |
|---|---|---|
| F695ZZ | 5 | 外輪を印刷座 `seat_od` に圧入、内輪に Ø4.95 ボスまたは Ø5 金属軸 |
| F685ZZ | 5 | 同上（手首系） |

配分: J1×2, J2×2, J3×1 (F695) / J4×2, J5×2, J6×1 (F685)

## ねじ推奨長さ（頭寸法: M3 Ø6×h2 / M4 Ø7×h2）

| 長さ | 用途 |
|---|---|
| M3×6–8 | サーボタブ、ホーン止め、薄いフランジ |
| M3×10–12 | 分割リンク（ダボ＋インサート×4） |
| M3×14–16 | グリッパ↔ヨーフランジ、カメラマウント |
| M4×8–12 | ベース板の机固定（PCD 100mm×4） |

インサート: M3 外径6mm（穴Ø5.9）、M4 外径5mm（穴Ø4.9）。高荷重は M3 優先。

## 軸

- 金属 Ø5 シャフト: 軸受通し（長さ＝頬間隔＋余裕5mm）
- 印刷ボス `SHAFT_FIT=4.95`: アイドラキャップを軸受内輪へ圧入＋M3止めねじ座

## 印刷パーツ ↔ 締結

| STL | 締結 |
|-----|---|
| 01_base_plate | M4×4 据付（接着なし） |
| 02_base_column | MG996Rタブねじ、F695ZZ圧入 |
| 03_turret | ホーンねじ、F695×3座、M3インサート、ソフトストッパ一体 |
| 04/05_shoulder_* | ホーンねじ / 圧入ボス＋M3 |
| 06/07_upper_arm_* | M3×4分割、肘サーボ、F695、ソフトストッパ |
| 08/09_elbow_* | ホーンねじ / 圧入ボス |
| 10/11_forearm_* | M3×4分割、F685×2 |
| 12–14_wrist_* | ホーンねじ、サーボタブ、F685、Ø5 |
| 15–18_gripper_* | MG90S、M3、リンクピン |
| 19–20_camera_* | ホーンねじ、M3 |

参照 STEP: `export/vendor/`

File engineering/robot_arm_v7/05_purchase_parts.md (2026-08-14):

# 購入部品一覧（事前）

| 購入ID | メーカー | 型番 | 数量 | 用途 | 状態 |
|---|---|---|---:|---|---|
| BUY-01 | MISUMI | E-SFJ5-40 | 5 | 5 mm精密軸。必要長へ切断 | 型番・納期再確認 |
| BUY-02 | MISUMI | SCSJ5-6 | 10 | 5 mm分割クランプカラー | 型番確認済み候補 |
| BUY-03 | Polymaker/Fiberon | PA12-CF10 1.75 mm 500 g | 2 | 構造部品 | 公式材料指定 |
| BUY-04 | PA12フィラメント | 銘柄未確定 | 1 | 遊星歯車 | 歯車試験片後に確定 |
| BUY-05 | Mean Well | LRS-50-5 | 1 | 5 V 10 Aサーボ電源候補 | 電装設計時に確認 |
| BUY-06 | 5 mmシム | SUS、ID5.1 | 選定後 | 軸方向すきま調整 | 厚さはCAD後決定 |
| BUY-07 | MISUMI | GBN1353GT-90 | 1 | J2 3GT×9、135 mmベルト | 型番確認済み候補 |
| BUY-08 | F685ZZ | 5×11×5、フランジ12.5×1 | 2 | J2入力軸支持 | 追加購入 |
| BUY-09 | F695ZZ | 5×13×4、フランジ15×1 | 1 | J2右出力支持 | 追加購入 |

購入はユーザー承認後に行う。本表は発注ではない。

## 参照

- TowerPro MG996R: https://towerpro.com.tw/product/mg996R/
- TowerPro MG90S: https://towerpro.com.tw/product/mg90s-3/
- NSK F695ZZ: https://www.oss.nsk.com/jp/products/bearings/ball-bearings/deep-groove-ball-bearings/extra-small-ball-bearings-and-miniature-ball-bearings-metric-series-with-flamge/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
- Fiberon PA12-CF10: https://fiberon.polymaker.com/product/pa12-cf10/

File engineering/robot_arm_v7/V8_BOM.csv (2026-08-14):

PartID | ObjectName | Label | BodyID | Qty | Material | ManufacturingMethod | Mass_g | ConnectionIDs
BELT-J2-135-3GT-90 | J2_BELT_135_3GT_90 | MISUMI GBN1353GT-90 closed timing belt | B1_TURNTABLE | 1 | Chloroprene rubber, fiberglass cord, nylon facing | Purchased MISUMI GBN1353GT-90 | 3.040 | C-J2-BELT
BR-685-1 | J1_PLANET_BRG_1 | F685ZZ planet bearing | B1_TURNTABLE | 1 | Bearing steel, ZZ shields | Purchased NSK F685ZZ | 2.180 | C-J1-P1
BR-685-2 | J1_PLANET_BRG_2 | F685ZZ planet bearing001 | B1_TURNTABLE | 1 | Bearing steel, ZZ shields | Purchased NSK F685ZZ | 2.180 | C-J1-P2
BR-685-3 | J1_PLANET_BRG_3 | F685ZZ planet bearing002 | B1_TURNTABLE | 1 | Bearing steel, ZZ shields | Purchased NSK F685ZZ | 2.180 | C-J1-P3
BR-695-1 | F695_J1_1 | F695ZZ J1 output bearing | B0_BASE | 1 | Bearing steel, ZZ shields | Purchased NSK F695ZZ | 2.840 | C-J1-BRG;C-J1-TRANSMISSION
BR-695-2 | F695_J1_2 | F695ZZ J1 output bearing001 | B0_BASE | 1 | Bearing steel, ZZ shields | Purchased NSK F695ZZ | 2.840 | C-J1-BRG;C-J1-TRANSMISSION
BR-F685_J2_INPUT_A | F685_J2_INPUT_A | F685ZZ002 | B1_TURNTABLE | 1 | Bearing steel, ZZ shields | Purchased NSK F685ZZ | 2.180 | C-J2-INPUT-SUPPORT;C-J2-BELT
BR-F685_J2_INPUT_B | F685_J2_INPUT_B | F685ZZ003 | B1_TURNTABLE | 1 | Bearing steel, ZZ shields | Purchased NSK F685ZZ | 2.180 | C-J2-INPUT-SUPPORT;C-J2-BELT
BR-F685_J5_A | F685_J5_A | F685ZZ | B4_WRIST_PITCH | 1 | Bearing steel, ZZ shields | Purchased NSK F685ZZ | 2.180 | C-J5-BRG
BR-F685_J5_B | F685_J5_B | F685ZZ001 | B4_WRIST_PITCH | 1 | Bearing steel, ZZ shields | Purchased NSK F685ZZ | 2.180 | C-J5-BRG
BR-F695_J2_L | F695_J2_L | F695ZZ | B2_UPPER_ARM | 1 | Bearing steel, ZZ shields | Purchased NSK F695ZZ | 2.840 | C-J2-OUTPUT-BEARINGS
BR-F695_J2_R | F695_J2_R | F695ZZ001 | B2_UPPER_ARM | 1 | Bearing steel, ZZ shields | Purchased NSK F695ZZ | 2.840 | C-J2-OUTPUT-BEARINGS
BR-F695_J3 | F695_J3 | F695ZZ002 | B2_UPPER_ARM | 1 | Bearing steel, ZZ shields | Purchased NSK F695ZZ | 2.840 | C-J3-PASSIVE
BR-F695_J4 | F695_J4 | F695ZZ003 | B3_FOREARM | 1 | Bearing steel, ZZ shields | Purchased NSK F695ZZ | 2.840 | C-J4-PASSIVE
COL-J3 | J3_COLLAR | J3 CL05M 5 mm set-screw collar | B3_FOREARM | 1 | Zinc-plated steel collar | Purchased Motionco CL05M; 5 ID x 10 OD x 5 W | 2.142 | C-J3-RETENTION;C-J3-PASSIVE
COL-J4 | J4_COLLAR | J4 CL05M 5 mm set-screw collar | B4_WRIST_PITCH | 1 | Zinc-plated steel collar | Purchased Motionco CL05M; 5 ID x 10 OD x 5 W | 2.142 | C-J4-RETENTION;C-J4-PASSIVE
COL-J5 | J5_OUTER_COLLAR | J5 CL05M 5 mm set-screw collar | B5_TOOL | 1 | Zinc-plated steel collar | Purchased Motionco CL05M; 5 ID x 10 OD x 5 W | 2.142 | C-J5-RETENTION
HORN-J1 | J1_STOCK_HORN | MG90S STEP double-arm horn | B0_BASE | 1 | Servo-supplied reinforced polymer horn | User STEP C:/Users/kohak/programs/robotarm/vendor/servo_cad/MG90S_HORN.step; +/-6.5 mm holes reamed 2.2 mm | 0.600 | C-J1-SUN-HORN
HORN-J4_SERVO | J4_SERVO_HORN | MG90S stock horn | B3_FOREARM | 1 | Servo-supplied reinforced polymer horn | User STEP C:/Users/kohak/programs/robotarm/vendor/servo_cad/MG90S_HORN.step; holes at +/-6.5 mm reamed for M3 | 0.600 | C-J4-SERVO;C-J4-ACTIVE
HORN-J5 | J5_STOCK_HORN | MG90S STEP double-arm horn001 | B4_WRIST_PITCH | 1 | Servo-supplied reinforced polymer horn | User STEP C:/Users/kohak/programs/robotarm/vendor/servo_cad/MG90S_HORN.step; +/-6.5 mm holes reamed 2.2 mm | 0.600 | C-J5-ACTIVE
INS-BASE_M4_1 | BASE_M4_1 | M4 heat-set insert OD5 L6 | B-1_FIXTURE | 1 | Brass heat-set insert | Thermal press-fit; coupon-calibrated hole | 0.360 | C-BASE-01
INS-BASE_M4_2 | BASE_M4_2 | M4 heat-set insert OD5 L007 | B-1_FIXTURE | 1 | Brass heat-set insert | Thermal press-fit; coupon-calibrated hole | 0.360 | C-BASE-01
INS-BASE_M4_3 | BASE_M4_3 | M4 heat-set insert OD5 L008 | B-1_FIXTURE | 1 | Brass heat-set insert | Thermal press-fit; coupon-calibrated hole | 0.360 | C-BASE-01
INS-BASE_M4_4 | BASE_M4_4 | M4 heat-set insert OD5 L009 | B-1_FIXTURE | 1 | Brass heat-set insert | Thermal press-fit; coupon-calibrated hole | 0.360 | C-BASE-01
INS-J1-HORN-M2-1 | J1_HORN_INSERT_M2_1 | M2 heat-set insert OD3.5 L3 | B1_TURNTABLE | 1 | Brass heat-set insert | Purchased; thermal press-fit after coupon calibration | 0.165 | C-J1-SUN-HORN
INS-J1-HORN-M2-2 | J1_HORN_INSERT_M2_2 | M2 heat-set insert OD3.5 L004 | B1_TURNTABLE | 1 | Brass heat-set insert | Purchased; thermal press-fit after coupon calibration | 0.165 | C-J1-SUN-HORN
INS-J1-SERVO-1 | J1_SERVO_1 | M2 heat-set insert OD3.5 L005 | B0_BASE | 1 | Brass heat-set insert | Purchased; thermal press-fit after coupon calibration | 0.165 | C-J1-SERVO
INS-J1-SERVO-2 | J1_SERVO_2 | M2 heat-set insert OD3.5 L006 | B0_BASE | 1 | Brass heat-set insert | Purchased; thermal press-fit after coupon calibration | 0.165 | C-J1-SERVO
INS-J1_CASE_1 | J1_CASE_1 | M3 heat-set insert OD6 L4 | B0_BASE | 1 | Brass heat-set insert | Thermal press-fit; coupon-calibrated hole | 0.721 | C-J1-RINGCASE
INS-J1_CASE_2 | J1_CASE_2 | M3 heat-set insert OD6 L005 | B0_BASE | 1 | Brass heat-set insert | Thermal press-fit; coupon-calibrated hole | 0.721 | C-J1-RINGCASE
INS-J1_CASE_3 | J1_CASE_3 | M3 heat-set insert OD6 L006 | B0_BASE | 1 | Brass heat-set insert | Thermal press-fit; coupon-calibrated hole | 0.721 | C-J1-RINGCASE
INS-J1_CASE_4 | J1_CASE_4 | M3 heat-set insert OD6 L007 | B0_BASE | 1 | Brass heat-set insert | Thermal press-fit; coupon-calibrated hole | 0.721 | C-J1-RINGCASE
INS-J1_CASE_5 | J1_CASE_5 | M3 heat-set insert OD6 L008 | B0_BASE | 1 | Brass heat-set insert | Thermal press-fit; coupon-calibrated hole | 0.721 | C-J1-RINGCASE
INS-J1_CASE_6 | J1_CASE_6 | M3 heat-set insert OD6 L009 | B0_BASE | 1 | Brass heat-set insert | Thermal press-fit; coupon-calibrated hole | 0.721 | C-J1-RINGCASE
INS-J1_OUTPUT_CLAMP | J1_OUTPUT_CLAMP | M3 heat-set insert OD6 L010 | B1_TURNTABLE | 1 | Brass heat-set insert | Thermal press-fit; coupon-calibrated hole | 0.721 | C-J1-OUTPUT-CLAMP
INS-J2_BRIDGE_INS_1 | J2_BRIDGE_INS_1 | M3 heat-set insert OD6 L022 | B1_TURNTABLE | 1 | Brass heat-set insert | Thermal press-fit; coupon-calibrated hole | 0.721 | C-J2-INPUT-SUPPORT
INS-J2_BRIDGE_INS_2 | J2_BRIDGE_INS_2 | M3 heat-set insert OD6 L023 | B1_TURNTABLE | 1 | Brass heat-set insert | Thermal press-fit; coupon-calibrated hole | 0.721 | C-J2-INPUT-SUPPORT
INS-J2_BRIDGE_INS_3 | J2_BRIDGE_INS_3 | M3 heat-set insert OD6 L024 | B1_TURNTABLE | 1 | Brass heat-set insert | Thermal press-fit; coupon-calibrated hole | 0.721 | C-J2-INPUT-SUPPORT
INS-J2_BRIDGE_INS_4 | J2_BRIDGE_INS_4 | M3 heat-set insert OD6 L025 | B1_TURNTABLE | 1 | Brass heat-set insert | Thermal press-fit; coupon-calibrated hole | 0.721 | C-J2-INPUT-SUPPORT
INS-J2_SERVO_1_1 | J2_SERVO_1_1 | M4 heat-set insert OD5 L4 | B1_TURNTABLE | 1 | Brass heat-set insert | Thermal press-fit; coupon-calibrated hole | 0.240 | C-J2-SERVO
INS-J2_SERVO_1_2 | J2_SERVO_1_2 | M4 heat-set insert OD5 L010 | B1_TURNTABLE | 1 | Brass heat-set insert | Thermal press-fit; coupon-calibrated hole | 0.240 | C-J2-SERVO
INS-J2_SERVO_2_1 | J2_SERVO_2_1 | M4 heat-set insert OD5 L011 | B1_TURNTABLE | 1 | Brass heat-set insert | Thermal press-fit; coupon-calibrated hole | 0.240 | C-J2-SERVO
INS-J2_SERVO_2_2 | J2_SERVO_2_2 | M4 heat-set insert OD5 L012 | B1_TURNTABLE | 1 | Brass heat-set insert | Thermal press-fit; coupon-calibrated hole | 0.240 | C-J2-SERVO
INS-J2_SHAFT_CLAMP_L | J2_SHAFT_CLAMP_L | M3 heat-set insert OD6 L011 | B1_TURNTABLE | 1 | Brass heat-set insert | Thermal press-fit; coupon-calibrated hole | 0.721 | C-J2-RETENTION
INS-J2_SHAFT_CLAMP_R | J2_SHAFT_CLAMP_R | M3 heat-set insert OD6 L012 | B1_TURNTABLE | 1 | Brass heat-set insert | Thermal press-fit; coupon-calibrated hole | 0.721 | C-J2-RETENTION
INS-J3_SERVO_1_1 | J3_SERVO_1_1 | M4 heat-set insert OD5 L013 | B2_UPPER_ARM | 1 | Brass heat-set insert | Thermal press-fit; coupon-calibrated hole | 0.240 | C-J3-SERVO
INS-J3_SERVO_1_2 | J3_SERVO_1_2 | M4 heat-set insert OD5 L014 | B2_UPPER_ARM | 1 | Brass heat-set insert | Thermal press-fit; coupon-calibrated hole | 0.240 | C-J3-SERVO
INS-J3_SERVO_2_1 | J3_SERVO_2_1 | M4 heat-set insert OD5 L015 | B2_UPPER_ARM | 1 | Brass heat-set insert | Thermal press-fit; coupon-calibrated hole | 0.240 | C-J3-SERVO
INS-J3_SERVO_2_2 | J3_SERVO_2_2 | M4 heat-set insert OD5 L016 | B2_UPPER_ARM | 1 | Brass heat-set insert | Thermal press-fit; coupon-calibrated hole | 0.240 | C-J3-SERVO
INS-J4_HORN_1 | J4_HORN_1 | M3 heat-set insert OD6 L026 | B4_WRIST_PITCH | 1 | Brass heat-set insert | Thermal press-fit; coupon-calibrated hole | 0.721 | C-J4-ACTIVE
INS-J4_HORN_2 | J4_HORN_2 | M3 heat-set insert OD6 L027 | B4_WRIST_PITCH | 1 | Brass heat-set insert | Thermal press-fit; coupon-calibrated hole | 0.721 | C-J4-ACTIVE
INS-J4_SERVO_1_1 | J4_SERVO_1_1 | M2 heat-set insert OD3.5 L007 | B3_FOREARM | 1 | Brass heat-set insert | Thermal press-fit; coupon-calibrated hole | 0.165 | C-J4-SERVO
INS-J4_SERVO_1_2 | J4_SERVO_1_2 | M2 heat-set insert OD3.5 L008 | B3_FOREARM | 1 | Brass heat-set insert | Thermal press-fit; coupon-calibrated hole | 0.165 | C-J4-SERVO
INS-J5-H-1-1 | J5_HOUSING_INS_1_1 | M3 heat-set insert OD6 L017 | B4_WRIST_PITCH | 1 | Brass heat-set insert | Thermal press-fit | 0.721 | C-J5-HOUSING
INS-J5-H-1-2 | J5_HOUSING_INS_1_2 | M3 heat-set insert OD6 L018 | B4_WRIST_PITCH | 1 | Brass heat-set insert | Thermal press-fit | 0.721 | C-J5-HOUSING
INS-J5-H-2-1 | J5_HOUSING_INS_2_1 | M3 heat-set insert OD6 L019 | B4_WRIST_PITCH | 1 | Brass heat-set insert | Thermal press-fit | 0.721 | C-J5-HOUSING
INS-J5-H-2-2 | J5_HOUSING_INS_2_2 | M3 heat-set insert OD6 L020 | B4_WRIST_PITCH | 1 | Brass heat-set insert | Thermal press-fit | 0.721 | C-J5-HOUSING
INS-J5-SERVO-1 | J5_SERVO_1 | M2 heat-set insert OD3.5 L009 | B4_WRIST_PITCH | 1 | Brass heat-set insert | Thermal press-fit after coupon calibration | 0.165 | C-J5-SERVO
INS-J5-SERVO-2 | J5_SERVO_2 | M2 heat-set insert OD3.5 L010 | B4_WRIST_PITCH | 1 | Brass heat-set insert | Thermal press-fit after coupon calibration | 0.165 | C-J5-SERVO
INS-J5_TOOL_CLAMP | J5_TOOL_CLAMP | M3 heat-set insert OD6 L021 | B5_TOOL | 1 | Brass heat-set insert | Thermal press-fit; coupon-calibrated hole | 0.721 | C-J5-TOOL
INS-UA_SPACER_1_L | UA_SPACER_1_L | M3 heat-set insert OD6 L013 | B2_UPPER_ARM | 1 | Brass heat-set insert | Thermal press-fit; coupon-calibrated hole | 0.721 | C-UA-CROSS
INS-UA_SPACER_1_R | UA_SPACER_1_R | M3 heat-set insert OD6 L014 | B2_UPPER_ARM | 1 | Brass heat-set insert | Thermal press-fit; coupon-calibrated hole | 0.721 | C-UA-CROSS
INS-UA_SPACER_2_L | UA_SPACER_2_L | M3 heat-set insert OD6 L015 | B2_UPPER_ARM | 1 | Brass heat-set insert | Thermal press-fit; coupon-calibrated hole | 0.721 | C-UA-CROSS
INS-UA_SPACER_2_R | UA_SPACER_2_R | M3 heat-set insert OD6 L016 | B2_UPPER_ARM | 1 | Brass heat-set insert | Thermal press-fit; coupon-calibrated hole | 0.721 | C-UA-CROSS
NUT-J5-HORN-M2-1 | J5_HORN_NUT_M2_1 | M2 prevailing-torque nut | B5_TOOL | 1 | Steel locknut | Purchased | 0.126 | C-J5-ACTIVE
NUT-J5-HORN-M2-2 | J5_HORN_NUT_M2_2 | M2 prevailing-torque nut001 | B5_TOOL | 1 | Steel locknut | Purchased | 0.126 | C-J5-ACTIVE
PR-B01 | BASE_PLATE | Base plate OD88 pocketed for exact MG90S STEP body | B0_BASE | 1 | Fiberon PA12-CF10 | FDM; 8 perimeters; 35% gyroid; M2 pillar coupon required | 36.238 | C-BASE-01;C-J1-SERVO
PR-E01 | GRIPPER_CRADLE | One-piece compact gripper cradle | B5_TOOL | 1 | Fiberon PA12-CF10 | FDM; 6 perimeters; one-piece cradle | 5.560 | C-TOOL-01;C-J5-TOOL
PR-HUB-J4 | J4_HORN_SPACER | J4 STEP-horn receiver bridge | B4_WRIST_PITCH | 1 | Fiberon PA12-CF10 | FDM; 8 perimeters; flat receiver for MG90S STEP horn | 2.025 | C-J4-ACTIVE
PR-HUB-J5 | J5_HORN_SHAFT_ADAPTER | J5 horn-to-5mm shaft adapter | B5_TOOL | 1 | Fiberon PA12-CF10 | FDM; 10 perimeters; ream 5H8 | 0.979 | C-J5-ACTIVE
PR-J1-R_J1_CarrierLower | V8_R_J1_CarrierLower | V7 lower carrier; 5 mm planet shafts V8 | B1_TURNTABLE | 1 | Fiberon PA12-CF10 | FDM | 5.155 | C-J1-TRANSMISSION
PR-J1-R_J1_CarrierUpper | V8_R_J1_CarrierUpper | V7 upper carrier; 5 mm planet shafts V8 | B1_TURNTABLE | 1 | Fiberon PA12-CF10 | FDM | 5.857 | C-J1-TRANSMISSION
PR-J1-R_J1_LowerHousing | V8_R_J1_LowerHousing | J1 compact lower case OD84; six M3 inserts | B0_BASE | 1 | Fiberon PA12-CF10 | FDM | 5.857 | C-J1-TRANSMISSION;C-J1-RINGCASE
PR-J1-R_J1_M5Shaft | V8_R_J1_M5Shaft | J1 5 mm output shaft cut 18 mm | B1_TURNTABLE | 1 | Steel shaft | Purchased/cut | 2.774 | C-J1-TRANSMISSION
PR-J1-R_J1_Planet1 | V8_R_J1_Planet1 | V7 24T m1.0 involute planet 1, F685 press-fit V8 | B1_TURNTABLE | 1 | PA12 | FDM | 3.647 | C-J1-TRANSMISSION;C-J1-P1
PR-J1-R_J1_Planet2 | V8_R_J1_Planet2 | V7 24T m1.0 involute planet 2, F685 press-fit V8 | B1_TURNTABLE | 1 | PA12 | FDM | 3.647 | C-J1-TRANSMISSION;C-J1-P2
PR-J1-R_J1_Planet3 | V8_R_J1_Planet3 | V7 24T m1.0 involute planet 3, F685 press-fit V8 | B1_TURNTABLE | 1 | PA12 | FDM | 3.647 | C-J1-TRANSMISSION;C-J1-P3
PR-J1-R_J1_RingGear | V8_R_J1_RingGear | V7 60T internal involute ring, 12 mm face V8 | B0_BASE | 1 | PA12 | FDM | 19.184 | C-J1-TRANSMISSION;C-J1-RINGCASE
PR-J1-R_J1_SunGear | V8_R_J1_SunGear | V7 12T m1.0 involute sun, 12 mm face V8 | B1_TURNTABLE | 1 | PA12 | FDM | 1.698 | C-J1-TRANSMISSION;C-J1-SUN-HORN
PR-J1-R_J1_Turntable | V8_R_J1_Turntable | Compact turntable 74 x 64 envelope | B1_TURNTABLE | 1 | Fiberon PA12-CF10 | FDM | 85.777 | C-J1-TRANSMISSION;C-J1-DECK;C-J2-SERVO;C-J2-OUTPUT-BEARINGS;C-J2-INPUT-SUPPORT;C-J1-OUTPUT-CLAMP;C-J2-RETENTION;C-J2-SERVO
PR-J1-R_J1_UpperHousing | V8_R_J1_UpperHousing | J1 compact upper case OD84; six M3 clearances | B0_BASE | 1 | Fiberon PA12-CF10 | FDM | 3.798 | C-J1-TRANSMISSION;C-J1-RINGCASE
PR-J2-IN-BRIDGE | J2_INPUT_BEARING_BRIDGE | J2 slotted dual-F685 input bridge | B1_TURNTABLE | 1 | Fiberon PA12-CF10 | FDM; 10 perimeters; press-fit F685 seats 10.96 mm plus flange counterbores; +/-1 mm alignment slots | 2.693 | C-J2-INPUT-SUPPORT
PR-J2-P16 | J2_DRIVER_16T | J2 printed 16T 3GT x 9 driver with split clamp | B1_TURNTABLE | 1 | PA12 | FDM; printed flat; tooth and split-clamp coupons required | 1.093 | C-J2-BELT;C-J2-INPUT-SUPPORT
PR-L01 | UPPER_ARM_L | UPPER ARM L | B2_UPPER_ARM | 1 | Fiberon PA12-CF10 | FDM; 6 perimeters; plates printed flat | 4.504 | C-J2-OUTPUT-BEARINGS;C-J3-PASSIVE;C-UA-CROSS
PR-L02 | UPPER_ARM_R | UPPER ARM R | B2_UPPER_ARM | 1 | Fiberon PA12-CF10 | FDM; 6 perimeters; plates printed flat | 4.504 | C-J2-BELT;C-J2-OUTPUT-BEARINGS;C-J3-SERVO;C-J3-PASSIVE;C-UA-CROSS;C-J3-SERVO
PR-L03 | FOREARM_L | FOREARM L | B3_FOREARM | 1 | Fiberon PA12-CF10 | FDM; 6 perimeters; plates printed flat | 4.504 | C-J3-ACTIVE;C-J4-PASSIVE;C-J4-SERVO
PR-L04 | FOREARM_R | FOREARM R | B3_FOREARM | 1 | Fiberon PA12-CF10 | FDM; 6 perimeters; plates printed flat | 4.504 | C-J3-PASSIVE;C-J4-SERVO
PR-UA-SP-1 | UPPER_ARM_SPACER_1 | Upper-arm M3 cross-spacer 1 | B2_UPPER_ARM | 1 | Fiberon PA12-CF10 | FDM flat; 8 perimeters; M3 inserts both ends | 5.251 | C-UA-CROSS
PR-UA-SP-2 | UPPER_ARM_SPACER_2 | Upper-arm M3 cross-spacer 2 | B2_UPPER_ARM | 1 | Fiberon PA12-CF10 | FDM flat; 8 perimeters; M3 inserts both ends | 5.251 | C-UA-CROSS
PR-W01 | WRIST_PITCH_L | WRIST PITCH L | B4_WRIST_PITCH | 1 | Fiberon PA12-CF10 | FDM; 6 perimeters; plates printed flat | 2.672 | C-J4-PASSIVE;C-J5-HOUSING
PR-W02 | WRIST_PITCH_R | WRIST PITCH R | B4_WRIST_PITCH | 1 | Fiberon PA12-CF10 | FDM; 6 perimeters; plates printed flat | 2.672 | C-J4-ACTIVE;C-J5-HOUSING;C-J5-SERVO
PR-W03 | J5_BEARING_HOUSING | J5 dual-bearing housing | B4_WRIST_PITCH | 1 | Fiberon PA12-CF10 | FDM; 8 perimeters; bearing bores reamed | 26.378 | C-J5-HOUSING;C-J5-BRG
SCR-BASE_M4X12_1 | BASE_M4X12_1 | M4x12 low-head screw | B0_BASE | 1 | Steel A2-70 | Purchased | 1.788 | C-BASE-01
SCR-BASE_M4X12_2 | BASE_M4X12_2 | M4x12 low-head screw001 | B0_BASE | 1 | Steel A2-70 | Purchased | 1.788 | C-BASE-01
SCR-BASE_M4X12_3 | BASE_M4X12_3 | M4x12 low-head screw002 | B0_BASE | 1 | Steel A2-70 | Purchased | 1.788 | C-BASE-01
SCR-BASE_M4X12_4 | BASE_M4X12_4 | M4x12 low-head screw003 | B0_BASE | 1 | Steel A2-70 | Purchased | 1.788 | C-BASE-01
SCR-J1-HORN-CENTER | J1_HORN_CENTER_SCREW | MG90S supplied horn center screw | B0_BASE | 1 | Steel servo screw | User STEP C:/Users/kohak/programs/robotarm/vendor/servo_cad/MG90S_SERVO.step | 0.234 | C-J1-SUN-HORN
SCR-J1-HORN-M2-1 | J1_HORN_M2_1 | M2x7 horn screw | B1_TURNTABLE | 1 | Steel A2-70 | Purchased M2x7 screw | 0.321 | C-J1-SUN-HORN
SCR-J1-HORN-M2-2 | J1_HORN_M2_2 | M2x7 horn screw001 | B1_TURNTABLE | 1 | Steel A2-70 | Purchased M2x7 screw | 0.321 | C-J1-SUN-HORN
SCR-J1-SERVO-1 | J1_SERVO_M2_1 | M2x8 low-head servo screw | B0_BASE | 1 | Steel A2-70 | Purchased M2x8 | 0.345 | C-J1-SERVO
SCR-J1-SERVO-2 | J1_SERVO_M2_2 | M2x8 low-head servo screw001 | B0_BASE | 1 | Steel A2-70 | Purchased M2x8 | 0.345 | C-J1-SERVO
SCR-J1_CASE_M3X20_1 | J1_CASE_M3X20_1 | M3x20 low-head screw | B0_BASE | 1 | Steel A2-70 | Purchased | 1.554 | C-J1-RINGCASE
SCR-J1_CASE_M3X20_2 | J1_CASE_M3X20_2 | M3x20 low-head screw001 | B0_BASE | 1 | Steel A2-70 | Purchased | 1.554 | C-J1-RINGCASE
SCR-J1_CASE_M3X20_3 | J1_CASE_M3X20_3 | M3x20 low-head screw002 | B0_BASE | 1 | Steel A2-70 | Purchased | 1.554 | C-J1-RINGCASE
SCR-J1_CASE_M3X20_4 | J1_CASE_M3X20_4 | M3x20 low-head screw003 | B0_BASE | 1 | Steel A2-70 | Purchased | 1.554 | C-J1-RINGCASE
SCR-J1_CASE_M3X20_5 | J1_CASE_M3X20_5 | M3x20 low-head screw004 | B0_BASE | 1 | Steel A2-70 | Purchased | 1.554 | C-J1-RINGCASE
SCR-J1_CASE_M3X20_6 | J1_CASE_M3X20_6 | M3x20 low-head screw005 | B0_BASE | 1 | Steel A2-70 | Purchased | 1.554 | C-J1-RINGCASE
SCR-J1_OUTPUT_CLAMP_M3 | J1_OUTPUT_CLAMP_M3 | M3x15 low-head screw | B1_TURNTABLE | 1 | Steel A2-70 | Purchased | 1.276 | C-J1-OUTPUT-CLAMP
SCR-J2_BRIDGE_M3_1 | J2_BRIDGE_M3_1 | M3x12 low-head screw | B1_TURNTABLE | 1 | Steel A2-70 | Purchased | 1.110 | C-J2-INPUT-SUPPORT
SCR-J2_BRIDGE_M3_2 | J2_BRIDGE_M3_2 | M3x12 low-head screw001 | B1_TURNTABLE | 1 | Steel A2-70 | Purchased | 1.110 | C-J2-INPUT-SUPPORT
SCR-J2_BRIDGE_M3_3 | J2_BRIDGE_M3_3 | M3x12 low-head screw002 | B1_TURNTABLE | 1 | Steel A2-70 | Purchased | 1.110 | C-J2-INPUT-SUPPORT
SCR-J2_BRIDGE_M3_4 | J2_BRIDGE_M3_4 | M3x12 low-head screw003 | B1_TURNTABLE | 1 | Steel A2-70 | Purchased | 1.110 | C-J2-INPUT-SUPPORT
SCR-J2_SERVO_M4_1_1 | J2_SERVO_M4_1_1 | M4x12 low-head screw004 | B1_TURNTABLE | 1 | Steel A2-70 | Purchased | 1.788 | C-J2-SERVO
SCR-J2_SERVO_M4_1_2 | J2_SERVO_M4_1_2 | M4x12 low-head screw005 | B1_TURNTABLE | 1 | Steel A2-70 | Purchased | 1.788 | C-J2-SERVO
SCR-J2_SERVO_M4_2_1 | J2_SERVO_M4_2_1 | M4x12 low-head screw006 | B1_TURNTABLE | 1 | Steel A2-70 | Purchased | 1.788 | C-J2-SERVO
SCR-J2_SERVO_M4_2_2 | J2_SERVO_M4_2_2 | M4x12 low-head screw007 | B1_TURNTABLE | 1 | Steel A2-70 | Purchased | 1.788 | C-J2-SERVO
SCR-J2_SHAFT_CLAMP_M3_L | J2_SHAFT_CLAMP_M3_L | M3x17 low-head screw | B1_TURNTABLE | 1 | Steel A2-70 | Purchased | 1.387 | C-J2-RETENTION
SCR-J2_SHAFT_CLAMP_M3_R | J2_SHAFT_CLAMP_M3_R | M3x17 low-head screw001 | B1_TURNTABLE | 1 | Steel A2-70 | Purchased | 1.387 | C-J2-RETENTION
SCR-J3_SERVO_M4_1_1 | J3_SERVO_M4_1_1 | M4x11 low-head screw | B2_UPPER_ARM | 1 | Steel A2-70 | Purchased | 1.689 | C-J3-SERVO
SCR-J3_SERVO_M4_1_2 | J3_SERVO_M4_1_2 | M4x11 low-head screw001 | B2_UPPER_ARM | 1 | Steel A2-70 | Purchased | 1.689 | C-J3-SERVO
SCR-J3_SERVO_M4_2_1 | J3_SERVO_M4_2_1 | M4x11 low-head screw002 | B2_UPPER_ARM | 1 | Steel A2-70 | Purchased | 1.689 | C-J3-SERVO
SCR-J3_SERVO_M4_2_2 | J3_SERVO_M4_2_2 | M4x11 low-head screw003 | B2_UPPER_ARM | 1 | Steel A2-70 | Purchased | 1.689 | C-J3-SERVO
SCR-J4-HORN-CENTER | J4_HORN_CENTER_SCREW | MG90S supplied horn center screw002 | B3_FOREARM | 1 | Steel servo screw | User STEP C:/Users/kohak/programs/robotarm/vendor/servo_cad/MG90S_SERVO.step | 0.234 | C-J4-ACTIVE
SCR-J4_HORN_M3_1 | J4_HORN_M3_1 | M3x15 low-head screw002 | B4_WRIST_PITCH | 1 | Steel A2-70 | Purchased | 1.276 | C-J4-ACTIVE
SCR-J4_HORN_M3_2 | J4_HORN_M3_2 | M3x15 low-head screw003 | B4_WRIST_PITCH | 1 | Steel A2-70 | Purchased | 1.276 | C-J4-ACTIVE
SCR-J4_SERVO_M2_1_1 | J4_SERVO_M2_1_1 | M2x8 low-head screw | B3_FOREARM | 1 | Steel A2-70 | Purchased | 0.395 | C-J4-SERVO
SCR-J4_SERVO_M2_1_2 | J4_SERVO_M2_1_2 | M2x8 low-head screw001 | B3_FOREARM | 1 | Steel A2-70 | Purchased | 0.395 | C-J4-SERVO
SCR-J5-H-1-1 | J5_HOUSING_M3_1_1 | M3x16 low-head housing screw | B4_WRIST_PITCH | 1 | Steel A2-70 | Purchased | 1.332 | C-J5-HOUSING
SCR-J5-H-1-2 | J5_HOUSING_M3_1_2 | M3x16 low-head housing screw001 | B4_WRIST_PITCH | 1 | Steel A2-70 | Purchased | 1.332 | C-J5-HOUSING
SCR-J5-H-2-1 | J5_HOUSING_M3_2_1 | M3x16 low-head housing screw002 | B4_WRIST_PITCH | 1 | Steel A2-70 | Purchased | 1.332 | C-J5-HOUSING
SCR-J5-H-2-2 | J5_HOUSING_M3_2_2 | M3x16 low-head housing screw003 | B4_WRIST_PITCH | 1 | Steel A2-70 | Purchased | 1.332 | C-J5-HOUSING
SCR-J5-HORN-CENTER | J5_HORN_CENTER_SCREW | MG90S supplied horn center screw001 | B4_WRIST_PITCH | 1 | Steel servo screw | User STEP C:/Users/kohak/programs/robotarm/vendor/servo_cad/MG90S_SERVO.step | 0.234 | C-J5-ACTIVE
SCR-J5-HORN-M2-1 | J5_HORN_M2_1 | M2x5 horn adapter bolt | B5_TOOL | 1 | Steel A2-70 | Purchased M2x5 screw + locknut | 0.271 | C-J5-ACTIVE
SCR-J5-HORN-M2-2 | J5_HORN_M2_2 | M2x5 horn adapter bolt001 | B5_TOOL | 1 | Steel A2-70 | Purchased M2x5 screw + locknut | 0.271 | C-J5-ACTIVE
SCR-J5-SERVO-1 | J5_SERVO_M2_1 | M2x8 low-head servo screw002 | B4_WRIST_PITCH | 1 | Steel A2-70 | Purchased M2x8 | 0.345 | C-J5-SERVO
SCR-J5-SERVO-2 | J5_SERVO_M2_2 | M2x8 low-head servo screw003 | B4_WRIST_PITCH | 1 | Steel A2-70 | Purchased M2x8 | 0.345 | C-J5-SERVO
SCR-J5_TOOL_CLAMP_M3 | J5_TOOL_CLAMP_M3 | M3x15 low-head screw001 | B5_TOOL | 1 | Steel A2-70 | Purchased | 1.276 | C-J5-TOOL
SCR-UA_SPACER_M3_1_L | UA_SPACER_M3_1_L | M3x9 low-head screw | B2_UPPER_ARM | 1 | Steel A2-70 | Purchased | 0.943 | C-UA-CROSS
SCR-UA_SPACER_M3_1_R | UA_SPACER_M3_1_R | M3x9 low-head screw001 | B2_UPPER_ARM | 1 | Steel A2-70 | Purchased | 0.943 | C-UA-CROSS
SCR-UA_SPACER_M3_2_L | UA_SPACER_M3_2_L | M3x9 low-head screw002 | B2_UPPER_ARM | 1 | Steel A2-70 | Purchased | 0.943 | C-UA-CROSS
SCR-UA_SPACER_M3_2_R | UA_SPACER_M3_2_R | M3x9 low-head screw003 | B2_UPPER_ARM | 1 | Steel A2-70 | Purchased | 0.943 | C-UA-CROSS
SER-J1 | J1_SERVO | TowerPro MG90S J1 exact STEP servo | B0_BASE | 1 | TowerPro MG90S purchased assembly | Unmodified user STEP C:/Users/kohak/programs/robotarm/vendor/servo_cad/MG90S_SERVO.step | 13.400 | C-J1-SERVO;C-J1-SUN-HORN
SER-J2_SERVO | J2_SERVO | TowerPro MG996R STEP assembly | B1_TURNTABLE | 1 | TowerPro MG996R purchased assembly | Unmodified user STEP C:/Users/kohak/programs/robotarm/vendor/servo_cad/MG996R_SERVO.step | 55.000 | C-J2-SERVO;C-J2-HORN-COUPLER
SER-J3_SERVO | J3_SERVO | TowerPro MG996R STEP assembly001 | B2_UPPER_ARM | 1 | TowerPro MG996R purchased assembly | Unmodified user STEP C:/Users/kohak/programs/robotarm/vendor/servo_cad/MG996R_SERVO.step | 55.000 | C-J3-SERVO;C-J3-ACTIVE
SER-J4_SERVO | J4_SERVO | TowerPro MG90S STEP assembly | B3_FOREARM | 1 | TowerPro MG90S purchased assembly | Unmodified user STEP C:/Users/kohak/programs/robotarm/vendor/servo_cad/MG90S_SERVO.step | 13.400 | C-J4-SERVO;C-J4-ACTIVE
SER-J5 | J5_SERVO | TowerPro MG90S J5 exact STEP servo | B4_WRIST_PITCH | 1 | TowerPro MG90S purchased assembly | Unmodified user STEP C:/Users/kohak/programs/robotarm/vendor/servo_cad/MG90S_SERVO.step | 13.400 | C-J5-SERVO;C-J5-ACTIVE
SET-J3 | J3_COLLAR_SETSCREW | CL05M included M3 set screw | B3_FOREARM | 1 | Steel | Included with Motionco CL05M | 0.222 | C-J3-RETENTION;C-J3-PASSIVE
SET-J4 | J4_COLLAR_SETSCREW | CL05M included M3 set screw001 | B4_WRIST_PITCH | 1 | Steel | Included with Motionco CL05M | 0.222 | C-J4-RETENTION;C-J4-PASSIVE
SET-J5 | J5_COLLAR_SETSCREW | CL05M included M3 set screw002 | B5_TOOL | 1 | Steel | Included with Motionco CL05M | 0.222 | C-J5-RETENTION
SH-J1-P1 | J1_PLANET_SHAFT_1 | J1 5 mm planet shaft | B1_TURNTABLE | 1 | Hardened steel shaft | Purchased 5 mm shaft; cut and deburr | 2.620 | C-J1-P1;C-J1-RETENTION;C-J1-TRANSMISSION
SH-J1-P2 | J1_PLANET_SHAFT_2 | J1 5 mm planet shaft001 | B1_TURNTABLE | 1 | Hardened steel shaft | Purchased 5 mm shaft; cut and deburr | 2.620 | C-J1-P2;C-J1-RETENTION;C-J1-TRANSMISSION
SH-J1-P3 | J1_PLANET_SHAFT_3 | J1 5 mm planet shaft002 | B1_TURNTABLE | 1 | Hardened steel shaft | Purchased 5 mm shaft; cut and deburr | 2.620 | C-J1-P3;C-J1-RETENTION;C-J1-TRANSMISSION
SH-J2-IN | J2_INPUT_SHAFT | J2 5 mm supported input shaft with flats | B1_TURNTABLE | 1 | Hardened steel shaft | Purchased E-SFJ5; cut 40 mm; two 0.5 mm flats | 6.165 | C-J2-HORN-COUPLER;C-J2-INPUT-SUPPORT;C-J2-BELT
SH-J2-OUT | J2_OUTPUT_SHAFT | J2 fixed 5 mm shoulder journal with two flats | B1_TURNTABLE | 1 | Hardened steel shaft | Purchased E-SFJ5; cut 102 mm; two 0.5 mm flats | 15.722 | C-J2-OUTPUT-BEARINGS;C-J2-RETENTION
SH-J3-P | J3_PASSIVE_STUB | J3 5 mm passive stub with machined flat | B3_FOREARM | 1 | Hardened steel shaft | Purchased 5 mm shaft; cut, deburr, mill 0.5 mm flat | 1.850 | C-J3-PASSIVE
SH-J4-P | J4_PASSIVE_STUB | J4 5 mm passive stub with machined flat | B4_WRIST_PITCH | 1 | Hardened steel shaft | Purchased 5 mm shaft; cut, deburr, mill 0.5 mm flat | 1.695 | C-J4-PASSIVE
SH-J5 | J5_OUTPUT_SHAFT | J5 5 mm output shaft | B5_TOOL | 1 | Hardened steel shaft | Purchased 5 mm shaft; cut and deburr | 4.316 | C-J5-ACTIVE;C-J5-BRG;C-J5-RETENTION;C-J5-TOOL

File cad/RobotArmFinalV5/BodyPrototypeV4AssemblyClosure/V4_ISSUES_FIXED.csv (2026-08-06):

interface | problem | fix
J1 bearing retention | B01/B02 lacked retainer screw interfaces | Added four M3 holes to each bearing seat
J5 bearing retention | Carrier had no holes matching retainer rings | Added four longitudinal M3 holes clamping both ends
J1 torque transfer | 75T gear had only a shaft hole | Added four-bolt gear/turntable/flange-hub stack
J4 torque transfer | 36T gear had no shaft clamp | Added three-bolt compact split gear hub
Servo pinions | Pinions could not bolt to the supplied horn | Added two horn screw holes and clamping washers
Flange hubs | Clamp screw had no head seat or nut restraint | Added head recess and anti-rotation nut pocket
Shaft axial retention | J1/J5 shafts could slide axially | Added two split shaft collars
Shoulder structure | Yoke plates were not mechanically attached to turntable | Added four adjustable L foot brackets
Link rigidity | Printed spacers had no dedicated corresponding holes | Added two spacer-bolt holes to each link pair
Wrist/J5 carrier | Only one bolt row aligned | Added the second row for four through-bolts
Servo mounting | J2-J5 servo bases floated outside the side plates | Added coaxial anchor frames and four standoff sets
J1 servo mounting | Servo base had no corresponding floor holes | Added four M4 holes and underside captive pockets

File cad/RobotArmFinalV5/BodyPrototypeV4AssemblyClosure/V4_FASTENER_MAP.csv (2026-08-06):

assembly | fastener | quantity | notes
J1 lower bearing retainer | M3x16 + nyloc nut | 4 | B10 to B01
J1 upper bearing retainer | M3x20 + nyloc nut | 4 | B10 to B02
J1 turntable + 75T gear + hub | M3x25 + nyloc nut | 4 | B16-B03-B09 stack
Shoulder yoke feet | M3x12 + nyloc nut | 12 | 4 brackets; two side screws and one base screw each
J2/J3/J4 bearing retainer + servo anchor | M3x16 + nyloc nut | 12 | Four per driven pitch axis
J2 servo standoffs | M4x50 + nyloc nut | 4 | 38 mm printed standoffs
J3 servo standoffs | M4x45 + nyloc nut | 4 | 32 mm printed standoffs
J4 servo standoffs | M4x25 + nyloc nut | 4 | 12 mm printed standoffs
J5 servo standoffs | M4x16 + nyloc nut | 4 | 5 mm printed standoffs
Upper/forearm/wrist spacers | M3x40 + nyloc nut | 6 | Two dedicated spacer bolts per link pair
J5 carrier to wrist plates | M3x50 + nyloc nut | 4 | Four through-bolts
Split flange hubs | M3x16 + nyloc nut | 8 | Tangential clamp bolt
J4 gear split hub | M3x12 + nyloc nut | 4 | Three gear bolts plus one clamp bolt
Axial collars | M3x14 + nyloc nut | 2 | J1 bottom and J5 rear
J1 servo base | M4x16 + nyloc nut | 4 | Captive pockets under B01
Pinion to MG90S horn | M2x8 self-tapping/bolt | 4 | Two screws per pinion plus center horn screw

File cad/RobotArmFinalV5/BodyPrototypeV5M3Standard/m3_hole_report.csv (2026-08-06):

part | label | quantity | m3_holes | policy | valid | solids | details
B01_BASE_LOWER | J1 lower base with towers | 1 | 8 | INSERT_POSITIVE | True | 1 | [{"axis": 2, "span": 14.0, "mode": "INSERT_POSITIVE"}, {"axis": 2, "span": 14.0, "mode": "INSERT_POSITIVE"}, {"axis": 2, "span": 14.0, "mode": "INSERT_POSITIVE"}, {"axis": 2, "span": 14.0, "mode": "INSERT_POSITIVE"}, {"axis": 2, "span": 28.0, "mode": "INSERT_POSITIVE"}, {"axis": 2, "span": 28.0, "mode": "INSERT_POSITIVE"}, {"axis": 2, "span": 28.0, "mode": "INSERT_POSITIVE"}, {"axis": 2, "span": 28.0, "mode": "INSERT_POSITIVE"}]
B02_BASE_UPPER | J1 upper bearing bridge | 1 | 8 | HEAD_SIDE | True | 1 | [{"axis": 2, "span": 8.0, "mode": "HEAD_SIDE"}, {"axis": 2, "span": 8.0, "mode": "HEAD_SIDE"}, {"axis": 2, "span": 8.0, "mode": "HEAD_SIDE"}, {"axis": 2, "span": 8.0, "mode": "HEAD_SIDE"}, {"axis": 2, "span": 12.0, "mode": "HEAD_SIDE"}, {"axis": 2, "span": 12.0, "mode": "HEAD_SIDE"}, {"axis": 2, "span": 12.0, "mode": "HEAD_SIDE"}, {"axis": 2, "span": 12.0, "mode": "HEAD_SIDE"}]
B03_J1_TURNTABLE | J1 turntable | 1 | 8 | INSERT_POSITIVE | True | 1 | [{"axis": 2, "span": 8.0, "mode": "INSERT_POSITIVE"}, {"axis": 2, "span": 8.0, "mode": "INSERT_POSITIVE"}, {"axis": 2, "span": 8.0, "mode": "INSERT_POSITIVE"}, {"axis": 2, "span": 8.0, "mode": "INSERT_POSITIVE"}, {"axis": 2, "span": 8.0, "mode": "INSERT_POSITIVE"}, {"axis": 2, "span": 8.0, "mode": "INSERT_POSITIVE"}, {"axis": 2, "span": 8.0, "mode": "INSERT_POSITIVE"}, {"axis": 2, "span": 8.0, "mode": "INSERT_POSITIVE"}]
B04_SHOULDER_YOKE_PLATE | Shoulder yoke side plate | 1 | 8 | HEAD_SIDE | True | 1 | [{"axis": 2, "span": 6.0, "mode": "HEAD_SIDE"}, {"axis": 2, "span": 6.0, "mode": "HEAD_SIDE"}, {"axis": 2, "span": 6.0, "mode": "HEAD_SIDE"}, {"axis": 2, "span": 6.0, "mode": "HEAD_SIDE"}, {"axis": 2, "span": 6.0, "mode": "HEAD_SIDE"}, {"axis": 2, "span": 6.0, "mode": "HEAD_SIDE"}, {"axis": 2, "span": 6.0, "mode": "HEAD_SIDE"}, {"axis": 2, "span": 6.0, "mode": "HEAD_SIDE"}]
B05_UPPER_ARM_PLATE | Upper arm side plate | 1 | 10 | HEAD_SIDE | True | 1 | [{"axis": 2, "span": 5.5, "mode": "HEAD_SIDE"}, {"axis": 2, "span": 5.5, "mode": "HEAD_SIDE"}, {"axis": 2, "span": 5.5, "mode": "HEAD_SIDE"}, {"axis": 2, "span": 5.5, "mode": "HEAD_SIDE"}, {"axis": 2, "span": 5.5, "mode": "HEAD_SIDE"}, {"axis": 2, "span": 5.5, "mode": "HEAD_SIDE"}, {"axis": 2, "span": 5.5, "mode": "HEAD_SIDE"}, {"axis": 2, "span": 5.5, "mode": "HEAD_SIDE"}, {"axis": 2, "span": 5.5, "mode": "HEAD_SIDE"}, {"axis": 2, "span": 5.5, "mode": "HEAD_SIDE"}]
B06_FOREARM_PLATE | Forearm side plate | 1 | 10 | HEAD_SIDE | True | 1 | [{"axis": 2, "span": 5.5, "mode": "HEAD_SIDE"}, {"axis": 2, "span": 5.5, "mode": "HEAD_SIDE"}, {"axis": 2, "span": 5.5, "mode": "HEAD_SIDE"}, {"axis": 2, "span": 5.5, "mode": "HEAD_SIDE"}, {"axis": 2, "span": 5.5, "mode": "HEAD_SIDE"}, {"axis": 2, "span": 5.5, "mode": "HEAD_SIDE"}, {"axis": 2, "span": 5.5, "mode": "HEAD_SIDE"}, {"axis": 2, "span": 5.5, "mode": "HEAD_SIDE"}, {"axis": 2, "span": 5.5, "mode": "HEAD_SIDE"}, {"axis": 2, "span": 5.5, "mode": "HEAD_SIDE"}]
B07_WRIST_PITCH_PLATE | Wrist pitch side plate | 1 | 10 | HEAD_SIDE | True | 1 | [{"axis": 2, "span": 5.5, "mode": "HEAD_SIDE"}, {"axis": 2, "span": 5.5, "mode": "HEAD_SIDE"}, {"axis": 2, "span": 5.5, "mode": "HEAD_SIDE"}, {"axis": 2, "span": 5.5, "mode": "HEAD_SIDE"}, {"axis": 2, "span": 5.5, "mode": "HEAD_SIDE"}, {"axis": 2, "span": 5.5, "mode": "HEAD_SIDE"}, {"axis": 2, "span": 5.5, "mode": "HEAD_SIDE"}, {"axis": 2, "span": 5.5, "mode": "HEAD_SIDE"}, {"axis": 2, "span": 5.5, "mode": "HEAD_SIDE"}, {"axis": 2, "span": 5.5, "mode": "HEAD_SIDE"}]
B08_J5_BEARING_CARRIER | J5 two-bearing roll carrier | 1 | 8 | INSERT_BOTH | True | 1 | [{"axis": 0, "span": 44.0, "mode": "INSERT_BOTH"}, {"axis": 0, "span": 44.0, "mode": "INSERT_BOTH"}, {"axis": 0, "span": 44.0, "mode": "INSERT_BOTH"}, {"axis": 0, "span": 44.0, "mode": "INSERT_BOTH"}, {"axis": 1, "span": 34.0, "mode": "INSERT_BOTH"}, {"axis": 1, "span": 34.0, "mode": "INSERT_BOTH"}, {"axis": 1, "span": 34.0, "mode": "INSERT_BOTH"}, {"axis": 1, "span": 34.0, "mode": "INSERT_BOTH"}]
B09_M5_SPLIT_FLANGE_HUB | M5 split flange hub | 1 | 5 | INSERT_POSITIVE | True | 1 | [{"axis": 2, "span": 4.0, "mode": "INSERT_POSITIVE_SKIPPED_THIN"}, {"axis": 2, "span": 4.0, "mode": "INSERT_POSITIVE_SKIPPED_THIN"}, {"axis": 2, "span": 4.0, "mode": "INSERT_POSITIVE_SKIPPED_THIN"}, {"axis": 1, "span": 17.964, "mode": "INSERT_POSITIVE"}, {"axis": 2, "span": 4.0, "mode": "INSERT_POSITIVE_SKIPPED_THIN"}]
B10_F695ZZ_RETAINER | F695ZZ retainer ring | 1 | 4 | HEAD_SIDE | True | 1 | [{"axis": 2, "span": 2.2, "mode": "HEAD_SIDE"}, {"axis": 2, "span": 2.2, "mode": "HEAD_SIDE"}, {"axis": 2, "span": 2.2, "mode": "HEAD_SIDE"}, {"axis": 2, "span": 2.2, "mode": "HEAD_SIDE"}]
B11_LINK_SPACER_28 | 28 mm link spacer | 1 | 1 | INSERT_BOTH | True | 1 | [{"axis": 2, "span": 28.0, "mode": "INSERT_BOTH"}]
B12_YOKE_SPACER_38 | 38 mm yoke spacer | 1 | 1 | INSERT_BOTH | True | 1 | [{"axis": 2, "span": 38.0, "mode": "INSERT_BOTH"}]
B13_FIXED_GRIPPER_PALM | Fixed gripper palm | 1 | 8 | INSERT_POSITIVE | True | 1 | [{"axis": 2, "span": 8.0, "mode": "INSERT_POSITIVE"}, {"axis": 2, "span": 8.0, "mode": "INSERT_POSITIVE"}, {"axis": 2, "span": 8.0, "mode": "INSERT_POSITIVE"}, {"axis": 2, "span": 8.0, "mode": "INSERT_POSITIVE"}, {"axis": 2, "span": 8.0, "mode": "INSERT_POSITIVE"}, {"axis": 2, "span": 8.0, "mode": "INSERT_POSITIVE"}, {"axis": 2, "span": 8.0, "mode": "INSERT_POSITIVE"}, {"axis": 2, "span": 8.0, "mode": "INSERT_POSITIVE"}]
B14_FIXED_GRIPPER_FINGER | Fixed gripper finger | 1 | 2 | HEAD_SIDE | True | 1 | [{"axis": 2, "span": 10.0, "mode": "HEAD_SIDE"}, {"axis": 2, "span": 10.0, "mode": "HEAD_SIDE"}]
B16_J1_OUTPUT_GEAR_75T | J1 75T output gear | 1 | 4 | HEAD_SIDE | True | 1 | [{"axis": 2, "span": 14.0, "mode": "HEAD_SIDE"}, {"axis": 2, "span": 14.0, "mode": "HEAD_SIDE"}, {"axis": 2, "span": 14.0, "mode": "HEAD_SIDE"}, {"axis": 2, "span": 14.0, "mode": "HEAD_SIDE"}]
B18_J4_OUTPUT_GEAR_36T | J4 36T output gear | 1 | 3 | HEAD_SIDE | True | 1 | [{"axis": 2, "span": 10.0, "mode": "HEAD_SIDE"}, {"axis": 2, "span": 10.0, "mode": "HEAD_SIDE"}, {"axis": 2, "span": 10.0, "mode": "HEAD_SIDE"}]
B19_MG90S_ADJUSTABLE_BASE | MG90S adjustable base | 1 | 0 | HEAD_SIDE | True | 1 | []
B20_MG90S_SLIDING_JAW | MG90S sliding jaw | 1 | 0 | INSERT_POSITIVE | True | 1 | []
B21_MG90S_CABLE_STOP | MG90S cable stop | 1 | 0 | INSERT_POSITIVE | True | 1 | []
B22_MG996R_ADJUSTABLE_BASE | MG996R adjustable base | 1 | 0 | HEAD_SIDE | True | 1 | []
B23_MG996R_SLIDING_JAW | MG996R sliding jaw | 1 | 0 | INSERT_POSITIVE | True | 1 | []
B24_SERVO_EAR_CLAMP | Servo ear clamp | 1 | 4 | HEAD_SIDE | True | 1 | [{"axis": 2, "span": 5.0, "mode": "HEAD_SIDE"}, {"axis": 2, "span": 5.0, "mode": "HEAD_SIDE"}, {"axis": 2, "span": 5.0, "mode": "HEAD_SIDE"}, {"axis": 2, "span": 5.0, "mode": "HEAD_SIDE"}]
B25_PRINTED_SHAFT_J1 | J1 temporary printed shaft 4.8 x 52 mm | 1 | 0 | HEAD_SIDE | True | 1 | []
B26_PRINTED_SHAFT_J2 | J2 temporary printed shaft 4.8 x 64 mm | 1 | 0 | HEAD_SIDE | True | 1 | []
B27_PRINTED_SHAFT_J3 | J3 temporary printed shaft 4.8 x 53 mm | 1 | 0 | HEAD_SIDE | True | 1 | []
B28_PRINTED_SHAFT_J4 | J4 temporary printed shaft 4.8 x 53 mm | 1 | 0 | HEAD_SIDE | True | 1 | []
B29_PRINTED_SHAFT_J5 | J5 temporary printed shaft 4.8 x 48 mm | 1 | 0 | HEAD_SIDE | True | 1 | []
B30_SHOULDER_FOOT_BRACKET | Shoulder yoke adjustable foot bracket | 1 | 4 | INSERT_BOTH | True | 1 | [{"axis": 1, "span": 4.0, "mode": "INSERT_BOTH_SKIPPED_THIN"}, {"axis": 1, "span": 4.0, "mode": "INSERT_BOTH_SKIPPED_THIN"}, {"axis": 2, "span": 4.0, "mode": "INSERT_BOTH_SKIPPED_THIN"}, {"axis": 2, "span": 4.0, "mode": "INSERT_BOTH_SKIPPED_THIN"}]
B31_J4_GEAR_SPLIT_HUB | J4 output gear split clamp hub | 1 | 4 | INSERT_POSITIVE | True | 1 | [{"axis": 1, "span": 14.7, "mode": "INSERT_POSITIVE"}, {"axis": 2, "span": 8.0, "mode": "INSERT_POSITIVE"}, {"axis": 2, "span": 8.0, "mode": "INSERT_POSITIVE"}, {"axis": 2, "span": 8.0, "mode": "INSERT_POSITIVE"}]
B32_MG996R_AXIS_ANCHOR | MG996R coaxial servo anchor frame | 1 | 4 | HEAD_SIDE | True | 1 | [{"axis": 2, "span": 4.0, "mode": "HEAD_SIDE"}, {"axis": 2, "span": 4.0, "mode": "HEAD_SIDE"}, {"axis": 2, "span": 4.0, "mode": "HEAD_SIDE"}, {"axis": 2, "span": 4.0, "mode": "HEAD_SIDE"}]
B33_MG90S_AXIS_ANCHOR | MG90S coaxial servo anchor frame | 1 | 4 | HEAD_SIDE | True | 1 | [{"axis": 2, "span": 4.0, "mode": "HEAD_SIDE"}, {"axis": 2, "span": 4.0, "mode": "HEAD_SIDE"}, {"axis": 2, "span": 4.0, "mode": "HEAD_SIDE"}, {"axis": 2, "span": 4.0, "mode": "HEAD_SIDE"}]
B34_M4_STANDOFF_38 | M4 servo standoff 38 mm | 1 | 0 | CLEARANCE_ONLY | True | 1 | []
B35_M4_STANDOFF_32 | M4 servo standoff 32 mm | 1 | 0 | CLEARANCE_ONLY | True | 1 | []
B36_M4_STANDOFF_12 | M4 servo standoff 12 mm | 1 | 0 | CLEARANCE_ONLY | True | 1 | []
B37_M4_STANDOFF_5 | M4 servo standoff 5 mm | 1 | 0 | CLEARANCE_ONLY | True | 1 | []
B38_M5_SPLIT_SHAFT_COLLAR | M5/printed-shaft split axial collar | 1 | 1 | INSERT_POSITIVE | True | 1 | [{"axis": 1, "span": 10.2, "mode": "INSERT_POSITIVE"}]
B39_MG90S_HORN_WASHER | MG90S horn clamping washer | 1 | 0 | CLEARANCE_ONLY | True | 1 | []
B40_J1_HORN_DRIVEN_PINION | J1 12T pinion with cross-horn drive socket | 1 | 0 | HEAD_SIDE | True | 1 | []
B41_J4_HORN_DRIVEN_PINION | J4 12T pinion with hollow cross-horn bridge | 1 | 0 | HEAD_SIDE | True | 1 | []
B42_J1_RISER_POST_36 | J1 upper bridge riser post 36 mm | 4 | 1 | CLEARANCE_ONLY | True | 1 | [{"axis": 2, "span": 36.0, "mode": "CLEARANCE_ONLY"}]
B43_PRINTED_SHAFT_J1_88 | J1 printed shaft 4.8 x 88 mm | 1 | 0 | HEAD_SIDE | True | 1 | []

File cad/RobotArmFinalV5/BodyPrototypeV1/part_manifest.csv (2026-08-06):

name | label | quantity | size_x_mm | size_y_mm | size_z_mm | volume_mm3 | orientation | notes
B01_BASE_LOWER | J1 lower base with towers | 1 | 140.0 | 140.0 | 36.0 | 175246.905 | bottom face on bed | F695ZZ lower seat
B02_BASE_UPPER | J1 upper bearing bridge | 1 | 100.0 | 100.0 | 12.0 | 82184.627 | large face on bed | F695ZZ upper seat
B03_J1_TURNTABLE | J1 turntable | 1 | 99.995 | 99.998 | 8.0 | 62107.967 | flat | Bolts to hub
B04_SHOULDER_YOKE_PLATE | Shoulder yoke side plate | 2 | 60.0 | 101.999 | 6.0 | 21138.985 | flat | J2 bearing support
B05_UPPER_ARM_PLATE | Upper arm side plate | 2 | 113.999 | 32.0 | 5.5 | 15152.002 | flat | 82 mm
B06_FOREARM_PLATE | Forearm side plate | 2 | 101.999 | 32.0 | 5.5 | 13832.002 | flat | 70 mm
B07_WRIST_PITCH_PLATE | Wrist pitch side plate | 2 | 75.999 | 30.0 | 5.5 | 11074.132 | flat | 46 mm
B08_J5_BEARING_CARRIER | J5 two-bearing roll carrier | 1 | 44.0 | 34.0 | 34.0 | 37850.164 | rear end on bed | Two F695ZZ seats
B09_M5_SPLIT_FLANGE_HUB | M5 split flange hub | 8 | 33.998 | 33.999 | 12.0 | 6058.686 | flange on bed | Link torque hub
B10_F695ZZ_RETAINER | F695ZZ retainer ring | 10 | 23.843 | 23.843 | 2.2 | 740.567 | flat | Bearing retainer
B11_LINK_SPACER_28 | 28 mm link spacer | 6 | 10.0 | 10.0 | 28.0 | 1959.631 | axis vertical | M3 through
B12_YOKE_SPACER_38 | 38 mm yoke spacer | 3 | 10.0 | 10.0 | 38.0 | 2659.5 | axis vertical | M3 through
B13_FIXED_GRIPPER_PALM | Fixed gripper palm | 1 | 42.0 | 50.0 | 8.0 | 15904.433 | flat | Fixed tool
B14_FIXED_GRIPPER_FINGER | Fixed gripper finger | 2 | 62.0 | 12.0 | 10.0 | 6173.678 | flat | Fixed fingers
B15_J1_PINION_12T | J1 12T pinion | 1 | 17.483 | 17.483 | 14.0 | 1897.856 | gear flat | Validated gear
B16_J1_OUTPUT_GEAR_75T | J1 75T output gear | 1 | 96.223 | 96.245 | 14.0 | 71287.122 | gear flat | Validated gear
B17_J4_PINION_12T | J4 12T pinion | 1 | 11.189 | 11.189 | 9.0 | 580.468 | gear flat | Validated gear
B18_J4_OUTPUT_GEAR_36T | J4 36T output gear | 1 | 30.394 | 30.394 | 10.0 | 5175.856 | gear flat | Validated gear
B19_MG90S_ADJUSTABLE_BASE | MG90S adjustable base | 3 | 52.0 | 38.0 | 4.0 | 4845.86 | flat | Adjustable mount
B20_MG90S_SLIDING_JAW | MG90S sliding jaw | 3 | 13.0 | 34.0 | 24.0 | 2896.993 | flat | Adjustable mount
B21_MG90S_CABLE_STOP | MG90S cable stop | 3 | 36.0 | 12.0 | 20.0 | 3416.478 | flat | Adjustable mount
B22_MG996R_ADJUSTABLE_BASE | MG996R adjustable base | 2 | 75.0 | 54.0 | 5.0 | 12467.316 | flat | Adjustable mount
B23_MG996R_SLIDING_JAW | MG996R sliding jaw | 2 | 18.0 | 50.0 | 34.0 | 7438.78 | flat | Adjustable mount
B24_SERVO_EAR_CLAMP | Servo ear clamp | 5 | 64.0 | 10.0 | 5.0 | 2456.289 | flat | Adjustable mount

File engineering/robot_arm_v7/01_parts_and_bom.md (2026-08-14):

# 事前部品一覧・BOM

## 支給部品

| 部品ID | 品名 | 型式・寸法 | 数量 | 配置 |
|---|---|---|---:|---|
| SER-J1 | マイクロサーボ | TowerPro MG90S | 1 | J1遊星入力 |
| SER-J2 | 標準サーボ | TowerPro MG996R | 1 | 肩ピッチ |
| SER-J3 | 標準サーボ | TowerPro MG996R | 1 | 肘ピッチ |
| SER-J4 | マイクロサーボ | TowerPro MG90S | 1 | 手首ピッチ |
| SER-J5 | マイクロサーボ | TowerPro MG90S | 1 | 手首ロール |
| SER-SP1..3 | 予備サーボ | TowerPro MG90S | 3 | 予備 |
| BR-695-1..2 | フランジ軸受 | F695ZZ、5x13x4、フランジ15x1 | 2 | J1出力上下 |
| BR-695-3..4 | フランジ軸受 | F695ZZ | 2 | J2出力左右 |
| BR-695-5 | フランジ軸受 | F695ZZ | 1 | J3反サーボ側 |
| BR-695-6 | フランジ軸受 | F695ZZ | 1 | J4反サーボ側 |
| BR-685-1..3 | 深溝軸受 | F685ZZ、5x11x5 | 3 | J1プラネット |
| BR-685-4..5 | 深溝軸受 | F685ZZ | 2 | J5出力支持 |
| BR-685-6..7 | 深溝軸受 | F685ZZ | 2 | J2入力軸支持 |
| BELT-J2 | タイミングベルト | MISUMI GBN1353GT-90 | 1 | J2 16T/32T減速 |
| SCR-M3-* | 低頭M3ねじ | 頭径6、高さ2、L5～20 | 数量未確定 | 構造・サーボ・遊星 |
| SCR-M4-* | 低頭M4ねじ | 頭径7、高さ2、L5～12 | 数量未確定 | ベース・高荷重部 |
| INS-M3-* | M3熱圧入インサート | 外径6、長さ4 | 100 | PA12-CF部品、下穴は試験片で校正 |
| INS-M4-3..8 | M4熱圧入インサート | 外径5、長さ3～8 | 各30 | 長さを肉厚に合わせて選択 |

## 印刷部品

| 部品ID | 品名 | 材料 | 製法 | 密度 |
|---|---|---|---|---:|
| PR-B01 | ベースプレート | PA12-CF10 | FDM | 1.06 g/cm3 |
| PR-G01/02 | J1ギアケース上下 | PA12-CF10 | FDM | 1.06 g/cm3 |
| PR-G03 | 12Tサンギア | PA12 | FDM | 1.01 g/cm3暫定 |
| PR-G04..06 | 24Tプラネット | PA12 | FDM | 1.01 g/cm3暫定 |
| PR-G07 | 60T内歯リング | PA12 | FDM | 1.01 g/cm3暫定 |
| PR-G08/09 | キャリア上下 | PA12-CF10 | FDM | 1.06 g/cm3 |
| PR-S01/02 | 肩側板 | PA12-CF10 | FDM | 1.06 g/cm3 |
| PR-L01/02 | 上腕側板 | PA12-CF10 | FDM | 1.06 g/cm3 |
| PR-J2-P16/P32 | J2 3GTプーリー | PA12 | FDM、歯形クーポン必須 | 1.01 g/cm3 |
| PR-J2-IN-BRIDGE | J2二軸受支持橋 | PA12-CF10 | FDM | 1.06 g/cm3 |
| PR-L03/04 | 前腕側板 | PA12-CF10 | FDM | 1.06 g/cm3 |
| PR-W01..03 | 手首ハウジング | PA12-CF10 | FDM | 1.06 g/cm3 |
| PR-E01..03 | グリッパー | PA12-CF10 | FDM | 1.06 g/cm3 |

部品質量は最終CADの`Shape.Volume x Density`から自動再計算する。

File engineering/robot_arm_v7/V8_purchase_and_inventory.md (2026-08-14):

# V8 在庫・購入部品

## 手持ちから使用

| 品目 | 使用/保有 | 用途 |
|---|---:|---|
| F695ZZ 5×13×4、フランジ15×1 | 5/5 | J1×2、J2左、J3、J4 |
| F685ZZ 5×11×5、フランジ12.5×1 | 5/5 | J1惑星×3、J5×2 |
| MG996R | 2/2 | J2/J3 |
| MG90S | 3/6 | J1/J4/J5、予備3 |
| M3熱圧入インサート OD6×L4 | 24以上/100 | ケース、割締め、支持橋、上腕スペーサ等 |
| M4熱圧入インサート OD5 | L4×8、L6×4 | J2/J3サーボ、外部治具 |
| M3/M4低頭ねじ | BOM記載数 | M3頭Ø6×H2、M4頭Ø7×H2。手持ち長さ範囲内 |

## 追加購入・加工

| 購入ID | 品目・型番 | 数量 | 用途・加工 |
|---|---|---:|---|
| BUY-J2-01 | MISUMI `GBN1353GT-90`、3GT×9、周長135 | 1 | J2 2:1ベルト |
| BUY-J2-02 | F685ZZ 5×11×5 フランジ12.5×1 | 2 | J2入力プーリー両側支持 |
| BUY-J2-03 | F695ZZ 5×13×4 フランジ15×1 | 1 | J2右側出力支持。左側は手持ちを使用 |
| BUY-J2-04 | MISUMI `E-SFJ5-120`相当5 mm精密軸 | 1 | 102 mm肩軸と40 mm入力軸へ切断、0.5 mm平面加工 |
| BUY-05 | Motionco `CL05M` | 3 | J3/J4/J5抜け止め |
| BUY-06 | M2×7×2、M2×8×6、M2×5×2、M2ロックナット×2 | 1式 | MG90S耳・実ホーン締結 |
| BUY-07 | M2熱圧入インサート OD3.5×L3 | 8 | MG90S耳・J1ハブ |
| BUY-08 | Fiberon PA12-CF10、乾燥品 | 必要量 | 全構造部 |
| BUY-09 | PA12 | 必要量 | J1歯車、J2 16T/32T歯形 |

購入は実行していない。MG996Rホーンはサーボ付属の現物2個を測定して使用し、測定差0.1 mm以下になるまで代替ホーンや仮想円板をBOMへ入れない。完全な1行1部品表は `V8_BOM.csv` を正とする。

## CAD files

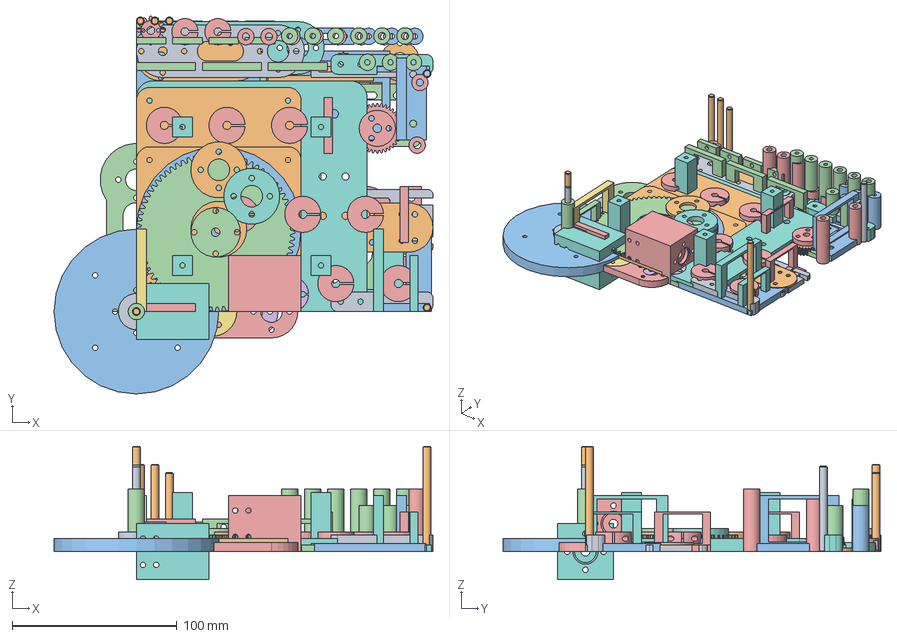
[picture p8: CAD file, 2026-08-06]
cad/RobotArmFinalV5/BodyPrototypeV4AssemblyClosure/ROBOT_ARM_BODY_PROTOTYPE_V4_ASSEMBLY_CLOSURE.FCStd
230.0 x 229.3 x 81.0 mm
J1 lower base with towers
J1 upper bearing bridge
J1 turntable
Shoulder yoke side plate
Upper arm side plate
Forearm side plate
Wrist pitch side plate
J5 two-bearing roll carrier
M5 split flange hub
F695ZZ retainer ring
28 mm link spacer
38 mm yoke spacer
Fixed gripper palm
Fixed gripper finger
J1 12T pinion
J1 75T output gear
J4 12T pinion
J4 36T output gear
MG90S adjustable base
MG90S sliding jaw
MG90S cable stop
MG996R adjustable base
MG996R sliding jaw
Servo ear clamp
J1 temporary printed shaft 4.8 x 52 mm
J2 temporary printed shaft 4.8 x 64 mm
J3 temporary printed shaft 4.8 x 53 mm
J4 temporary printed shaft 4.8 x 53 mm
J5 temporary printed shaft 4.8 x 48 mm
Shoulder yoke adjustable foot bracket
J4 output gear split clamp hub
MG996R coaxial servo anchor frame
MG90S coaxial servo anchor frame
M4 servo standoff 38 mm
M4 servo standoff 32 mm
M4 servo standoff 12 mm
M4 servo standoff 5 mm
M5/printed-shaft split axial collar
MG90S horn clamping washer
V4_PLATE_01
V4_PLATE_02
V4_PLATE_03
V4_PLATE_04
V4_PLATE_05
V4_PLATE_06
V4_PLATE_07

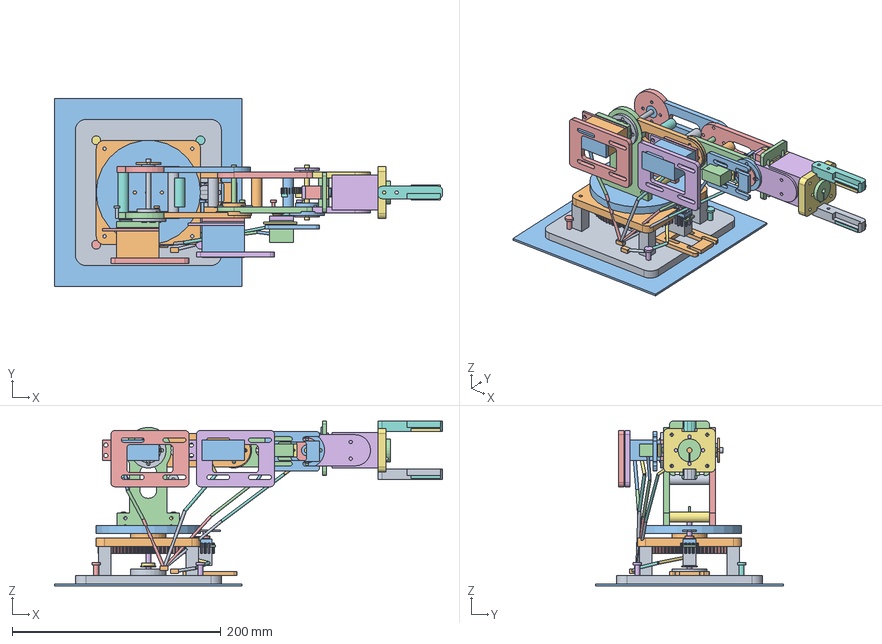
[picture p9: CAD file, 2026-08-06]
cad/RobotArmFinalV5/CompletedPreviewV1/ROBOT_ARM_COMPLETED_PREVIEW_V1.FCStd
372.0 x 180.0 x 158.0 mm
Base lower / bearing tower
Base upper bearing bridge
J1 rotating turntable
Shoulder yoke left
Shoulder yoke right
Yoke spacer 38 mm
Yoke spacer 38 mm001
Yoke spacer 38 mm002
Yoke spacer 38 mm003
Upper arm left
Upper arm right
Forearm left
Forearm right
Wrist pitch left
Wrist pitch right
Link spacer 28 mm
Link spacer 28 mm001
Link spacer 28 mm002
Link spacer 28 mm003
Link spacer 28 mm004
Link spacer 28 mm005
J5 two-bearing carrier
Fixed gripper palm
Fixed gripper finger Top
Fixed gripper finger Bottom
J1 MG90S adjustable cradle
J4 MG90S adjustable cradle
J5 MG90S adjustable cradle
J2 MG996R adjustable cradle
J3 MG996R adjustable cradle
Rubber grip pad Top
Rubber grip pad Bottom
TowerPro MG90S Housing
TowerPro MG90S Bottom
TowerPro MG90S Top
TowerPro MG90S MountingEars
TowerPro MG90S OutputBoss
TowerPro MG90S Spline
TowerPro MG90S MotorCap
TowerPro MG90S Label
TowerPro MG90S Horn
TowerPro MG996R Housing
TowerPro MG996R Bottom
TowerPro MG996R Top
TowerPro MG996R MountingEars
TowerPro MG996R OutputBoss
TowerPro MG996R Spline
TowerPro MG996R MotorCap
TowerPro MG996R Label
TowerPro MG996R Horn
TowerPro MG996R Housing001
TowerPro MG996R Bottom001
TowerPro MG996R Top001
TowerPro MG996R MountingEars001
TowerPro MG996R OutputBoss001
TowerPro MG996R Spline001
TowerPro MG996R MotorCap001
TowerPro MG996R Label001
TowerPro MG996R Horn001
TowerPro MG90S Housing001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

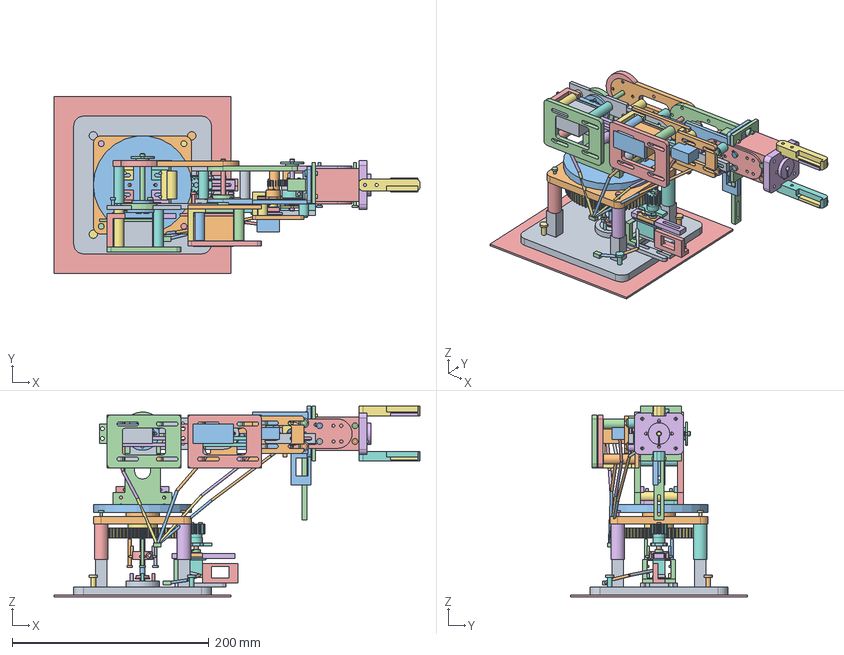
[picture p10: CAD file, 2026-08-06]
cad/RobotArmFinalV5/CompletedPreviewV4_1ServoTransmission/ROBOT_ARM_COMPLETED_PREVIEW_V4_1_SERVO_TRANSMISSION.FCStd
372.0 x 180.0 x 194.0 mm
Base lower / bearing tower
Base upper bearing bridge
J1 rotating turntable
Shoulder yoke left
Shoulder yoke right
Yoke spacer 38 mm
Yoke spacer 38 mm001
Yoke spacer 38 mm002
Upper arm left
Upper arm right
Forearm left
Forearm right
Wrist pitch left
Wrist pitch right
Link spacer 28 mm
Link spacer 28 mm001
Link spacer 28 mm002
Link spacer 28 mm003
Link spacer 28 mm004
Link spacer 28 mm005
J5 two-bearing carrier
Fixed gripper palm
Fixed gripper finger Top
Fixed gripper finger Bottom
J1 MG90S adjustable cradle
J4 MG90S adjustable cradle
J5 MG90S adjustable cradle
J2 MG996R adjustable cradle
J3 MG996R adjustable cradle
Rubber grip pad Top
Rubber grip pad Bottom
TowerPro MG90S Housing
TowerPro MG90S Bottom
TowerPro MG90S Top
TowerPro MG90S MountingEars
TowerPro MG90S OutputBoss
TowerPro MG90S Spline
TowerPro MG90S MotorCap
TowerPro MG90S Label
TowerPro MG90S Horn
TowerPro MG996R Housing
TowerPro MG996R Bottom
TowerPro MG996R Top
TowerPro MG996R MountingEars
TowerPro MG996R OutputBoss
TowerPro MG996R Spline
TowerPro MG996R MotorCap
TowerPro MG996R Label
TowerPro MG996R Horn
TowerPro MG996R Housing001
TowerPro MG996R Bottom001
TowerPro MG996R Top001
TowerPro MG996R MountingEars001
TowerPro MG996R OutputBoss001
TowerPro MG996R Spline001
TowerPro MG996R MotorCap001
TowerPro MG996R Label001
TowerPro MG996R Horn001
TowerPro MG90S Housing001
TowerPro MG90S Bottom001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

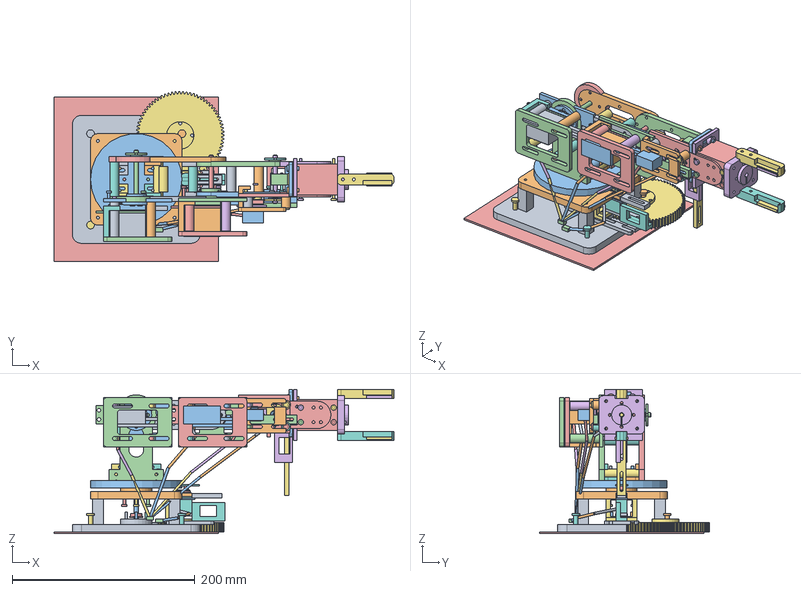
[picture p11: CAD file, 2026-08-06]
cad/RobotArmFinalV5/CompletedPreviewV4AssemblyClosure/ROBOT_ARM_COMPLETED_PREVIEW_V4_ASSEMBLY_CLOSURE.FCStd
372.0 x 186.2 x 158.0 mm
Base lower / bearing tower
Base upper bearing bridge
J1 rotating turntable
Shoulder yoke left
Shoulder yoke right
Yoke spacer 38 mm
Yoke spacer 38 mm001
Yoke spacer 38 mm002
Upper arm left
Upper arm right
Forearm left
Forearm right
Wrist pitch left
Wrist pitch right
Link spacer 28 mm
Link spacer 28 mm001
Link spacer 28 mm002
Link spacer 28 mm003
Link spacer 28 mm004
Link spacer 28 mm005
J5 two-bearing carrier
Fixed gripper palm
Fixed gripper finger Top
Fixed gripper finger Bottom
J1 MG90S adjustable cradle
J4 MG90S adjustable cradle
J5 MG90S adjustable cradle
J2 MG996R adjustable cradle
J3 MG996R adjustable cradle
Rubber grip pad Top
Rubber grip pad Bottom
TowerPro MG90S Housing
TowerPro MG90S Bottom
TowerPro MG90S Top
TowerPro MG90S MountingEars
TowerPro MG90S OutputBoss
TowerPro MG90S Spline
TowerPro MG90S MotorCap
TowerPro MG90S Label
TowerPro MG90S Horn
TowerPro MG996R Housing
TowerPro MG996R Bottom
TowerPro MG996R Top
TowerPro MG996R MountingEars
TowerPro MG996R OutputBoss
TowerPro MG996R Spline
TowerPro MG996R MotorCap
TowerPro MG996R Label
TowerPro MG996R Horn
TowerPro MG996R Housing001
TowerPro MG996R Bottom001
TowerPro MG996R Top001
TowerPro MG996R MountingEars001
TowerPro MG996R OutputBoss001
TowerPro MG996R Spline001
TowerPro MG996R MotorCap001
TowerPro MG996R Label001
TowerPro MG996R Horn001
TowerPro MG90S Housing001
TowerPro MG90S Bottom001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

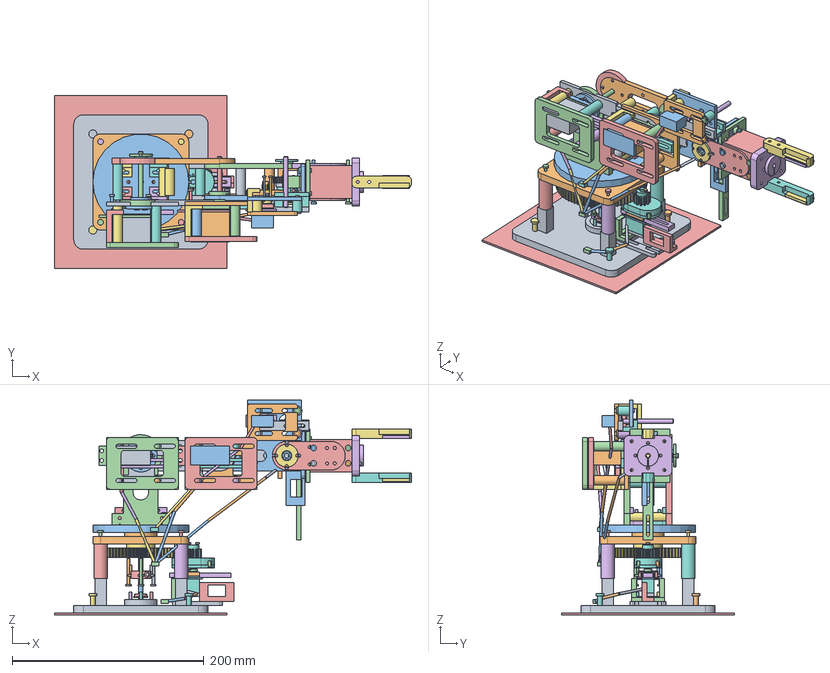
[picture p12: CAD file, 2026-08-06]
cad/RobotArmFinalV5/CompletedPreviewV5_1HornTransmission/ROBOT_ARM_COMPLETED_PREVIEW_V5_1_HORN_TRANSMISSION.FCStd
372.0 x 180.0 x 224.0 mm
Base lower / bearing tower
Base upper bearing bridge
J1 rotating turntable
Shoulder yoke left
Shoulder yoke right
Yoke spacer 38 mm
Yoke spacer 38 mm001
Yoke spacer 38 mm002
Upper arm left
Upper arm right
Forearm left
Forearm right
Wrist pitch left
Wrist pitch right
Link spacer 28 mm
Link spacer 28 mm001
Link spacer 28 mm002
Link spacer 28 mm003
Link spacer 28 mm004
Link spacer 28 mm005
J5 two-bearing carrier
Fixed gripper palm
Fixed gripper finger Top
Fixed gripper finger Bottom
J1 MG90S adjustable cradle
J4 MG90S adjustable cradle
J5 MG90S adjustable cradle
J2 MG996R adjustable cradle
J3 MG996R adjustable cradle
Rubber grip pad Top
Rubber grip pad Bottom
TowerPro MG90S Housing
TowerPro MG90S Bottom
TowerPro MG90S Top
TowerPro MG90S MountingEars
TowerPro MG90S OutputBoss
TowerPro MG90S Spline
TowerPro MG90S MotorCap
TowerPro MG90S Label
MG90S horn 36x19 mm
TowerPro MG996R Housing
TowerPro MG996R Bottom
TowerPro MG996R Top
TowerPro MG996R MountingEars
TowerPro MG996R OutputBoss
TowerPro MG996R Spline
TowerPro MG996R MotorCap
TowerPro MG996R Label
TowerPro MG996R Horn
TowerPro MG996R Housing001
TowerPro MG996R Bottom001
TowerPro MG996R Top001
TowerPro MG996R MountingEars001
TowerPro MG996R OutputBoss001
TowerPro MG996R Spline001
TowerPro MG996R MotorCap001
TowerPro MG996R Label001
TowerPro MG996R Horn001
TowerPro MG90S Housing001
TowerPro MG90S Bottom001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

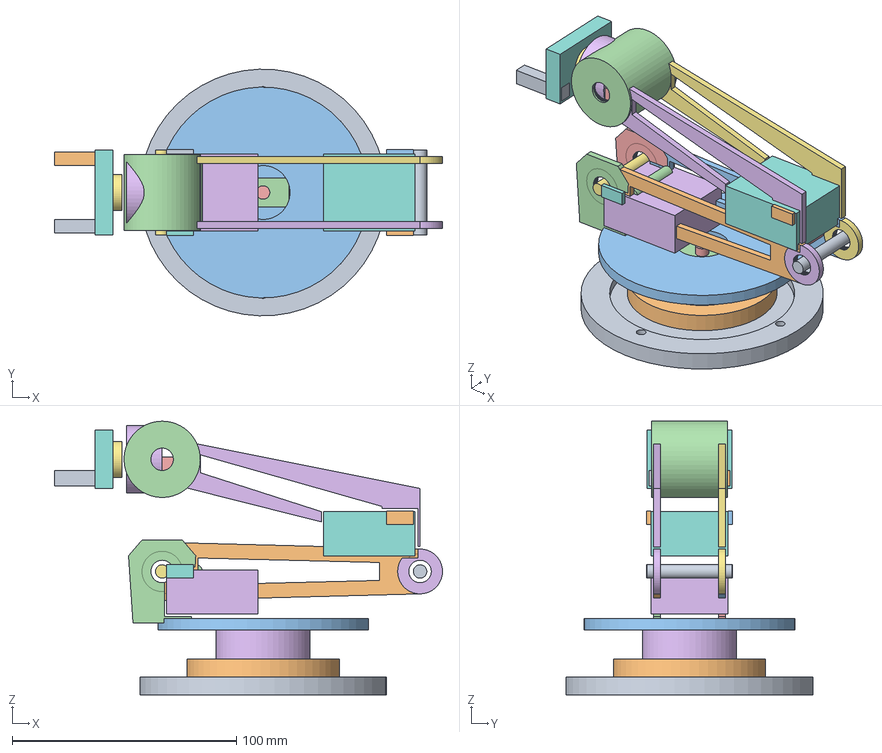
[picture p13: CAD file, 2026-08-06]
cad/RobotArmFinalV5/CompletedPreviewV5_2CradleAlignment/ROBOT_ARM_COMPLETED_PREVIEW_V6_COMPACT_PLANETARY.FCStd
173.0 x 109.9 x 122.0 mm
Compact base plate Ø110 × 8
J1 integrated lower bearing boss
Low-profile J1 turntable Ø94
MG90S vertical servo envelope
J1 servo spline / sun input
J1 60T fixed ring, m0.55 conceptual
J1 12T sun, m0.55 conceptual
J1 24T planet 1
J1 24T planet 2
J1 24T planet 3
J1 planetary output carrier
Shoulder plate L; integrated bearing boss
Shoulder plate R; integrated bearing boss
J2 MG996R embedded; plate is cradle
J2 M5 shoulder shaft
J2 fixed ear seat L; integral cradle interface
J2 fixed ear seat R; integral cradle interface
Tapered upper-arm I plate L
Tapered upper-arm I plate R
Upper arm minimal spacer 1
Upper arm minimal spacer 2
Tapered forearm I plate L
Tapered forearm I plate R
J3 MG996R embedded in forearm root
J3 M5 elbow shaft
J3 fixed ear seat L; integral forearm cradle
J3 fixed ear seat R; integral forearm cradle
Thin J4 pitch housing; integrated bosses
J4 compact servo envelope
J5 coax-near roll housing
J5 integrated output boss
Compact integrated gripper palm
Compact gripper finger L
Compact gripper finger R

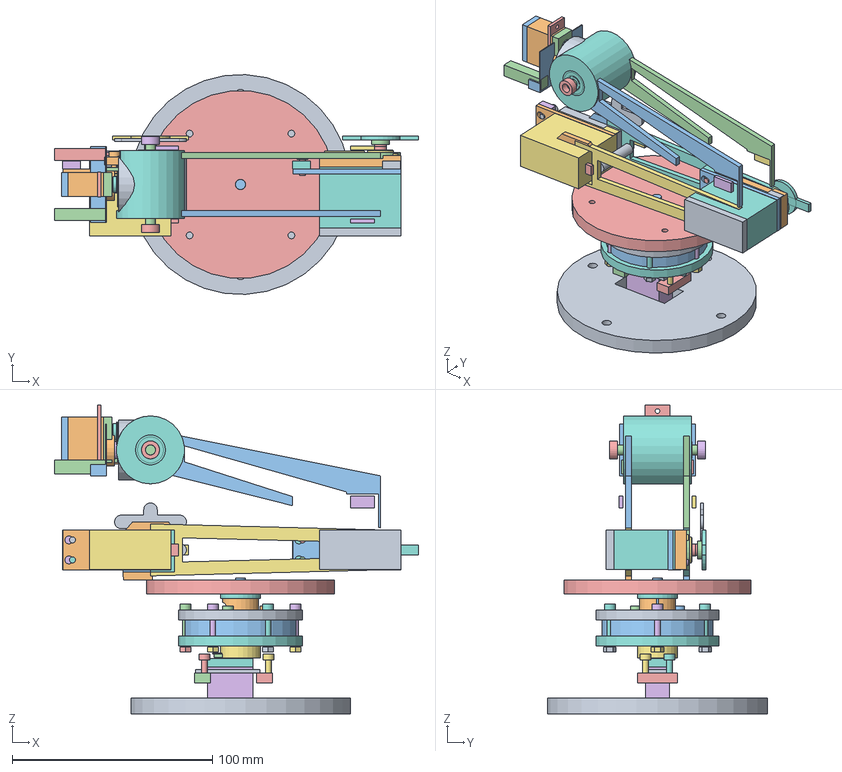
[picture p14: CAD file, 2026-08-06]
cad/RobotArmFinalV5/CompletedPreviewV5_2CradleAlignment/ROBOT_ARM_COMPLETED_PREVIEW_V6_1_REALISTIC_FDM.FCStd
182.0 x 109.9 x 154.4 mm
Compact base plate Ø110 × 8
Shoulder plate L; integrated bearing boss
Shoulder plate R; integrated bearing boss
J2 M5 shoulder shaft
J2 fixed ear seat L; integral cradle interface
J2 fixed ear seat R; integral cradle interface
Tapered upper-arm I plate L
Tapered upper-arm I plate R
Upper arm minimal spacer 1
Upper arm minimal spacer 2
Tapered forearm I plate L
Tapered forearm I plate R
J3 M5 elbow shaft
J3 fixed ear seat L; integral forearm cradle
J3 fixed ear seat R; integral forearm cradle
Thin J4 pitch housing; integrated bosses
J5 coax-near roll housing
J5 integrated output boss
Compact integrated gripper palm
Compact gripper finger L
Compact gripper finger R
J1 genuine TowerPro Housing
J1 genuine TowerPro Bottom
J1 genuine TowerPro Top
J1 genuine TowerPro MountingEars
J1 genuine TowerPro OutputBoss
J1 genuine TowerPro Spline
J1 genuine TowerPro MotorCap
J1 genuine TowerPro Label
J1 genuine TowerPro Horn
J2 genuine TowerPro Housing
J2 genuine TowerPro Bottom
J2 genuine TowerPro Top
J2 genuine TowerPro MountingEars
J2 genuine TowerPro OutputBoss
J2 genuine TowerPro Spline
J2 genuine TowerPro MotorCap
J2 genuine TowerPro Label
J2 genuine TowerPro Horn
J3 genuine TowerPro Housing
J3 genuine TowerPro Bottom
J3 genuine TowerPro Top
J3 genuine TowerPro MountingEars
J3 genuine TowerPro OutputBoss
J3 genuine TowerPro Spline
J3 genuine TowerPro MotorCap
J3 genuine TowerPro Label
J3 genuine TowerPro Horn
J4 genuine TowerPro Housing
J4 genuine TowerPro Bottom
J4 genuine TowerPro Top
J4 genuine TowerPro MountingEars
J4 genuine TowerPro OutputBoss
J4 genuine TowerPro Spline
J4 genuine TowerPro MotorCap
J4 genuine TowerPro Label
J4 genuine TowerPro Horn
J5 genuine TowerPro Housing
J5 genuine TowerPro Bottom
J5 genuine TowerPro Top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

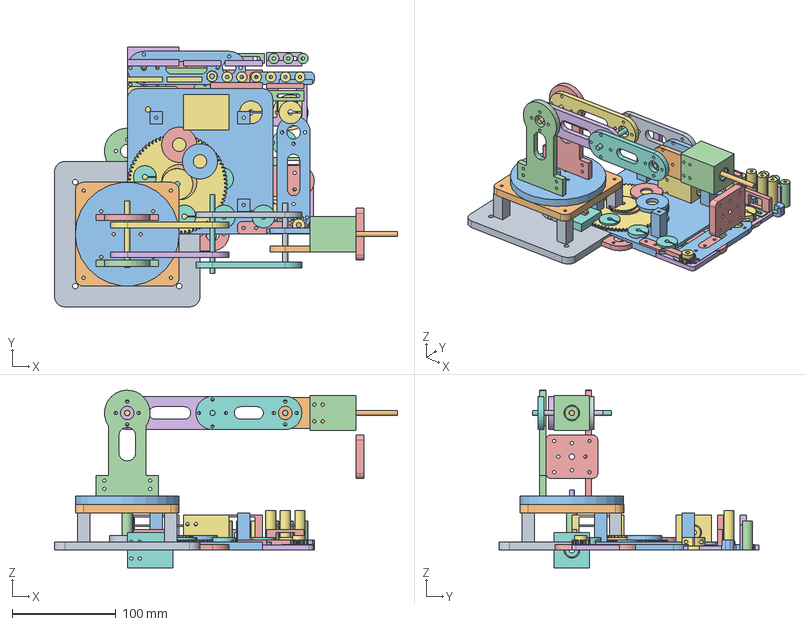
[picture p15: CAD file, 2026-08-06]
cad/RobotArmFinalV5/BodyPrototypeV1/ROBOT_ARM_BODY_PROTOTYPE_V1.FCStd
330.0 x 250.0 x 170.9 mm
J1 lower base with towers
J1 upper bearing bridge
J1 turntable
Shoulder yoke side plate
Upper arm side plate
Forearm side plate
Wrist pitch side plate
J5 two-bearing roll carrier
M5 split flange hub
F695ZZ retainer ring
28 mm link spacer
38 mm yoke spacer
Fixed gripper palm
Fixed gripper finger
J1 12T pinion
J1 75T output gear
J4 12T pinion
J4 36T output gear
MG90S adjustable base
MG90S sliding jaw
MG90S cable stop
MG996R adjustable base
MG996R sliding jaw
Servo ear clamp
A01_BASE
A02_UPPER
A03_TURN
A04_YOKE_L
A05_YOKE_R
A06_UPPER_L
A07_UPPER_R
A08_FORE_L
A09_FORE_R
A10_WRIST_L
A11_WRIST_R
A12_J5
A13_PALM
HW_J1_SHAFT
HW_J2_SHAFT
HW_J3_SHAFT
HW_J4_SHAFT
HW_J5_SHAFT
BODY_PLATE_01
BODY_PLATE_02
BODY_PLATE_03
BODY_PLATE_04
BODY_PLATE_05
BODY_PLATE_06

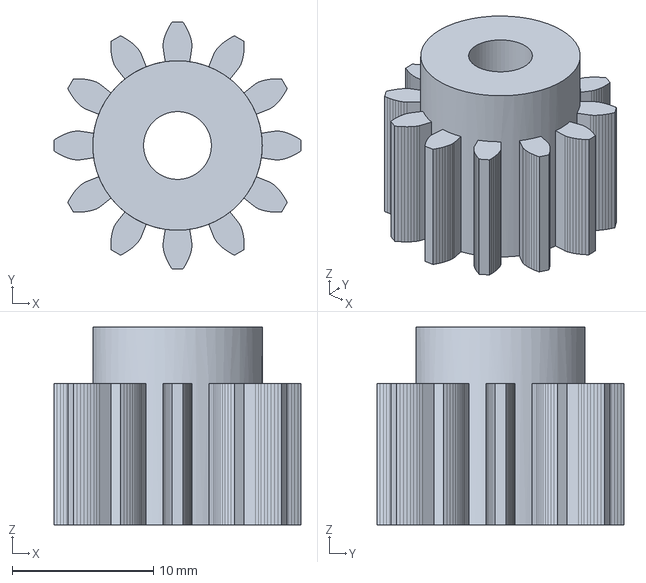
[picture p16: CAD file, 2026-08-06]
cad/RobotArmFinalV5/BodyPrototypeV1/STEP/B15_J1_PINION_12T.step
17.5 x 17.5 x 14.0 mm

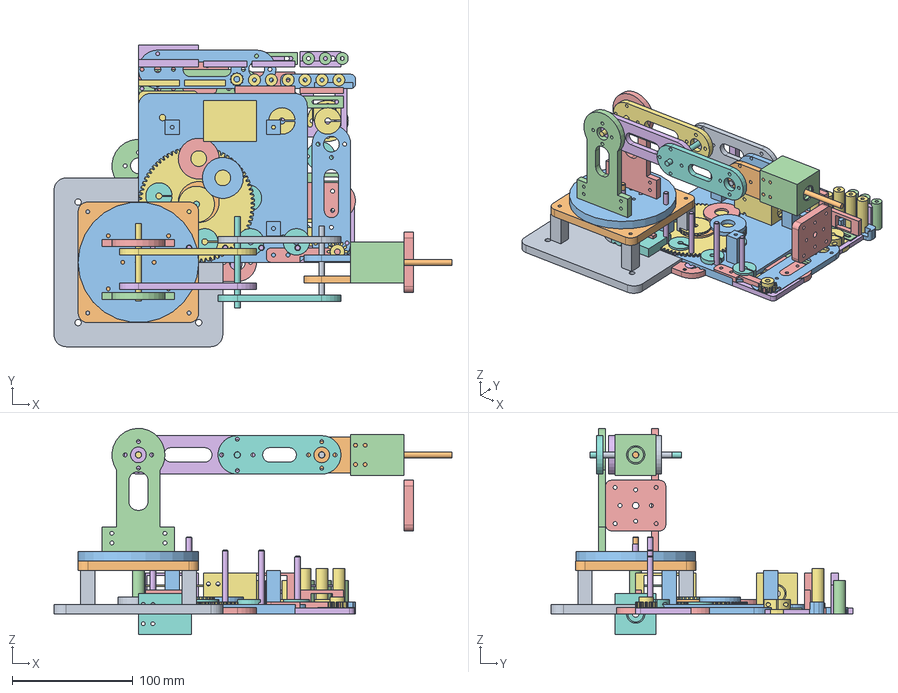
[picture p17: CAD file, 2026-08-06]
cad/RobotArmFinalV5/BodyPrototypeV2PrintedShafts/ROBOT_ARM_BODY_PROTOTYPE_V2_PRINTED_SHAFTS.FCStd
330.0 x 250.0 x 170.9 mm
J1 lower base with towers
J1 upper bearing bridge
J1 turntable
Shoulder yoke side plate
Upper arm side plate
Forearm side plate
Wrist pitch side plate
J5 two-bearing roll carrier
M5 split flange hub
F695ZZ retainer ring
28 mm link spacer
38 mm yoke spacer
Fixed gripper palm
Fixed gripper finger
J1 12T pinion
J1 75T output gear
J4 12T pinion
J4 36T output gear
MG90S adjustable base
MG90S sliding jaw
MG90S cable stop
MG996R adjustable base
MG996R sliding jaw
Servo ear clamp
A01_BASE
A02_UPPER
A03_TURN
A04_YOKE_L
A05_YOKE_R
A06_UPPER_L
A07_UPPER_R
A08_FORE_L
A09_FORE_R
A10_WRIST_L
A11_WRIST_R
A12_J5
A13_PALM
HW_J1_SHAFT
HW_J2_SHAFT
HW_J3_SHAFT
HW_J4_SHAFT
HW_J5_SHAFT
BODY_PLATE_01
BODY_PLATE_02
BODY_PLATE_03
BODY_PLATE_04
BODY_PLATE_05
BODY_PLATE_06
J1 temporary printed shaft 4.8 x 52 mm
J2 temporary printed shaft 4.8 x 64 mm
J3 temporary printed shaft 4.8 x 53 mm
J4 temporary printed shaft 4.8 x 53 mm
J5 temporary printed shaft 4.8 x 48 mm
Body plate 07 - five printed temporary shafts
Alternative plate 07B - horizontal printed shafts

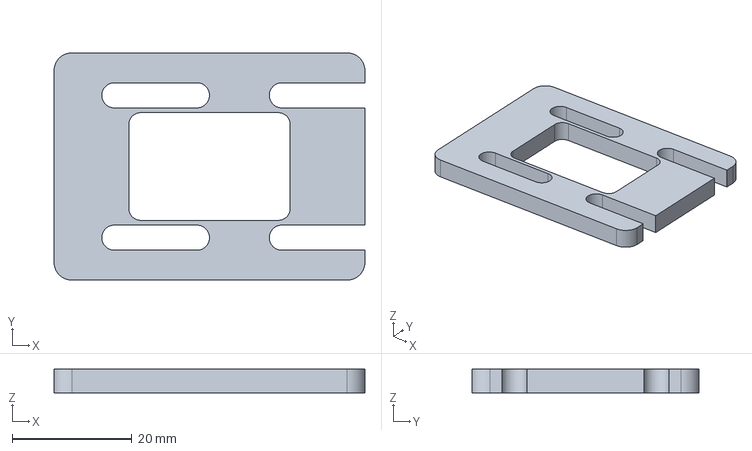
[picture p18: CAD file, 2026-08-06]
cad/RobotArmFinalV5/BodyPrototypeV2PrintedShafts/STEP/B19_MG90S_ADJUSTABLE_BASE.step
52.0 x 38.0 x 4.00 mm

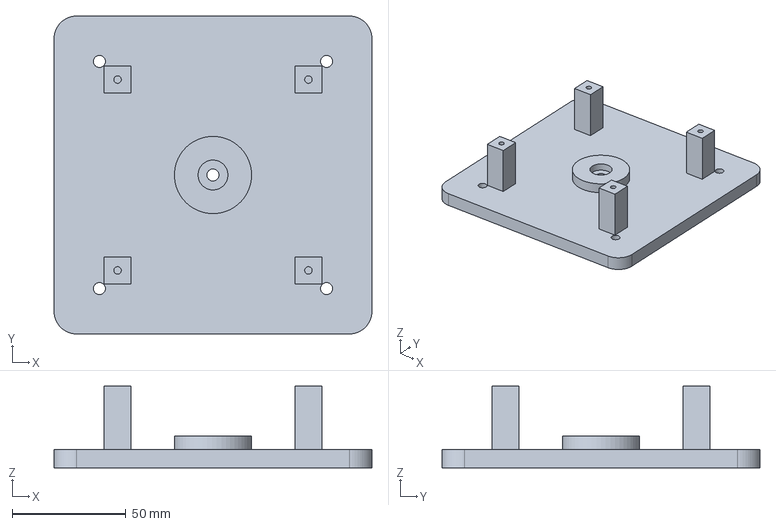
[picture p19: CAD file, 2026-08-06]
cad/RobotArmFinalV5/BodyPrototypeV3BearingClearance/STEP/B01_BASE_LOWER.step
140.0 x 140.0 x 36.0 mm

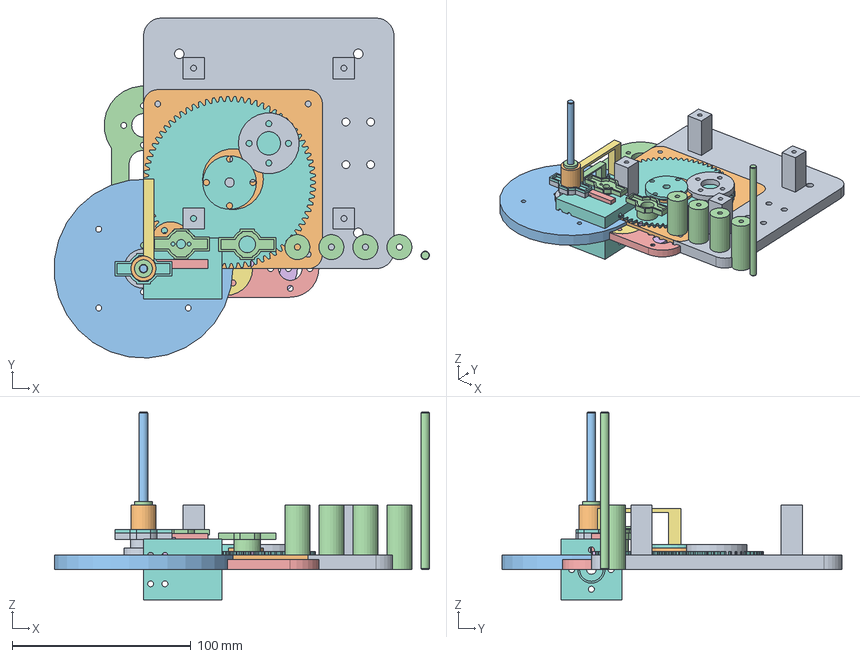
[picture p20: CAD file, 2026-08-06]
cad/RobotArmFinalV5/BodyPrototypeV4_1ServoTransmission/ROBOT_ARM_BODY_PROTOTYPE_V4_1_SERVO_TRANSMISSION.FCStd
209.5 x 189.9 x 105.0 mm
J1 lower base with towers
J1 upper bearing bridge
J1 turntable
Shoulder yoke side plate
Upper arm side plate
Forearm side plate
Wrist pitch side plate
J5 two-bearing roll carrier
M5 split flange hub
F695ZZ retainer ring
28 mm link spacer
38 mm yoke spacer
Fixed gripper palm
Fixed gripper finger
J1 12T pinion
J1 75T output gear
J4 12T pinion
J4 36T output gear
MG90S adjustable base
MG90S sliding jaw
MG90S cable stop
MG996R adjustable base
MG996R sliding jaw
Servo ear clamp
J1 temporary printed shaft 4.8 x 52 mm
J2 temporary printed shaft 4.8 x 64 mm
J3 temporary printed shaft 4.8 x 53 mm
J4 temporary printed shaft 4.8 x 53 mm
J5 temporary printed shaft 4.8 x 48 mm
Shoulder yoke adjustable foot bracket
J4 output gear split clamp hub
MG996R coaxial servo anchor frame
MG90S coaxial servo anchor frame
M4 servo standoff 38 mm
M4 servo standoff 32 mm
M4 servo standoff 12 mm
M4 servo standoff 5 mm
M5/printed-shaft split axial collar
MG90S horn clamping washer
J1 12T pinion with cross-horn drive socket
J4 12T pinion with hollow cross-horn bridge
J1 upper bridge riser post 36 mm
J1 printed shaft 4.8 x 88 mm
BODY_PLATE_08_SERVO_TRANSMISSION

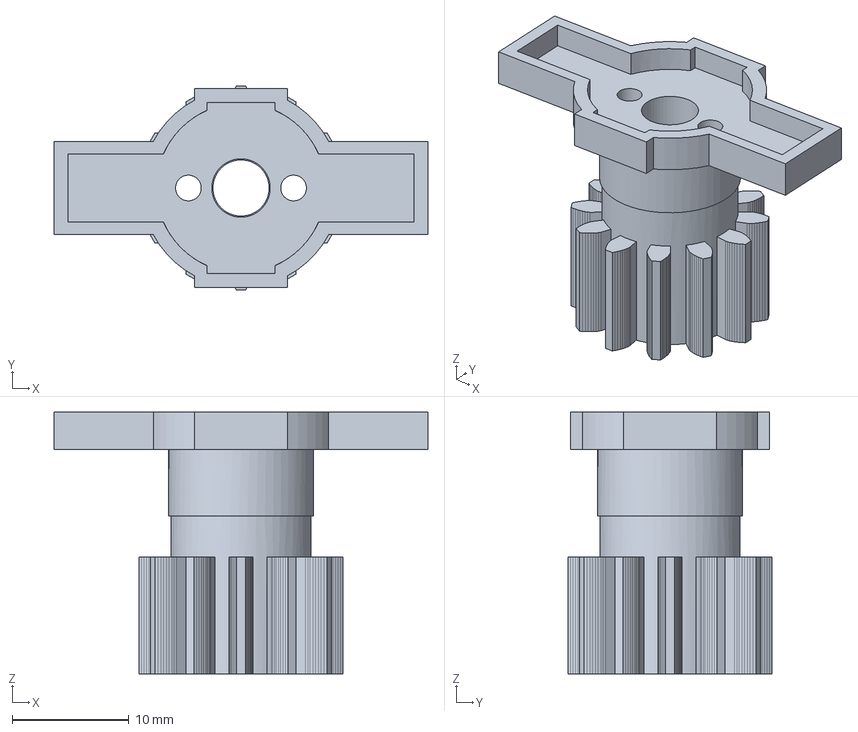
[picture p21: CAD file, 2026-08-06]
cad/RobotArmFinalV5/BodyPrototypeV4_1ServoTransmission/STEP/B40_J1_HORN_DRIVEN_PINION.step
32.0 x 17.5 x 22.4 mm

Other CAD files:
cad/RobotArmFinalV5/CompletedPreviewV2PrintedShafts/ROBOT_ARM_COMPLETED_PREVIEW_V2_PRINTED_SHAFTS.FCStd
cad/RobotArmFinalV5/CompletedPreviewV5_2CradleAlignment/ROBOT_ARM_COMPLETED_PREVIEW_V5_2_CRADLE_ALIGNMENT.FCStd
cad/RobotArmFinalV5/BodyPrototypeV3BearingClearance/ROBOT_ARM_BODY_PROTOTYPE_V3_BEARING_CLEARANCE.FCStd
cad/RobotArmFinalV5/BodyPrototypeV4AssemblyClosure/STEP/B33_MG90S_AXIS_ANCHOR.step
cad/RobotArmFinalV5/BodyPrototypeV1/STEP/B01_BASE_LOWER.step
cad/RobotArmFinalV5/BodyPrototypeV1/STEP/B02_BASE_UPPER.step
cad/RobotArmFinalV5/BodyPrototypeV1/STEP/B03_J1_TURNTABLE.step
cad/RobotArmFinalV5/BodyPrototypeV1/STEP/B04_SHOULDER_YOKE_PLATE.step
cad/RobotArmFinalV5/BodyPrototypeV1/STEP/B05_UPPER_ARM_PLATE.step
cad/RobotArmFinalV5/BodyPrototypeV1/STEP/B06_FOREARM_PLATE.step
cad/RobotArmFinalV5/BodyPrototypeV1/STEP/B07_WRIST_PITCH_PLATE.step
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

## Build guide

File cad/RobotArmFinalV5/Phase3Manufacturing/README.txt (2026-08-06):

Robot Arm Final V5 Phase 3 Manufacturing

This directory contains unique printable PartDesign bodies, STEP and STL exports, and fit coupons.
Print the coupons before structural parts. Do not force bearings or heat-set inserts into an unvalidated fit.
P05/P06/P07 are quantity-two mirrored side plates. P16/P17/P18 are quantity-five modular parts.
The gear tooth profiles are generated with sampled 20-degree involute flanks and must be verified with C04/C05 before loading the arm.
Final material, layer orientation and fastener lengths remain subject to bench testing.

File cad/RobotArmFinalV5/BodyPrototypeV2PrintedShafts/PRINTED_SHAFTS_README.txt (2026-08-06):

Diameter: 4.8 mm
Lengths: J1 52, J2 64, J3 53, J4 53, J5 48 mm
Use: no-load, low-speed temporary assembly only.
Vertical plate: no supports, use brim.
Horizontal plate: stronger, supports and sanding required.

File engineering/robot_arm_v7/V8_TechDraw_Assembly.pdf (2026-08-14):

ROBOT ARM V8 — ASSEMBLY / ENVELOPE

Reach 301 mm; base OD 88 mm; J2 transmission envelope <120 mm; shoulder axis Z=79 mm
Servo bodies: unmodified user STEP; J2/J3 M4 exact slots; J1/J4/J5 M2 exact holes Payload 50 g; 4.8 V; normal range J2 -90..0, J3 -90..90, J4 -60..60 deg
Fold corridor: J2=-80, J3 90..150, J4 0..-70 deg; see MuJoCo report

DO NOT SCALE. All dimensions in mm. See connection schedule for fastening details.

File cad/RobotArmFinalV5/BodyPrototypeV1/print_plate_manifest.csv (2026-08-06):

plate | x_mm | y_mm | z_mm | parts | minimum_bbox_gap_mm
BODY_PLATE_01 | 180.0 | 176.0 | 36.0 | 4 | 4.0
BODY_PLATE_02 | 174.0 | 174.0 | 28.0 | 11 | 4.0
BODY_PLATE_03 | 180.0 | 170.0 | 34.0 | 7 | 4.0
BODY_PLATE_04 | 179.0 | 180.0 | 34.0 | 9 | 4.0
BODY_PLATE_05 | 174.0 | 159.22 | 38.0 | 16 | 4.0
BODY_PLATE_06 | 175.84 | 127.69 | 12.0 | 17 | 4.0

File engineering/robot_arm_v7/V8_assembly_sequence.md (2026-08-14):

# V8 組立順序

1. 本番と同じ乾燥・造形方向でM2/M3/M4インサート、F685/F695座、3GT歯形、5 mm割締めのクーポンを造形する。引抜き、回転、圧入、歯飛び試験へ合格するまで本体を承認しない。
2. MG996Rホーン2個を `mg996_horn_measurements.json` の基準で独立測定する。対応寸法差≤0.10 mm、穴中心再現性≤0.05 mmを確認後だけ `status=VERIFIED` として再生成する。
3. 全印刷品を検査し、軸受座、通し穴、割締めスリットだけを仕上げる。層割れ、反り、ボイド品は使用しない。
4. J1 MG90Sを基台一体座へM2×8×2で固定し、実ホーン、太陽、惑星、F685×3、F695×2、ケース、5 mm出力軸、ターンテーブルを従来手順で組む。
5. ターンテーブル一体J2座へM4 OD5×L4を熱圧入し、実スロット4箇所をM4×12×4で仮締めする。サーボへ追加工しない。
6. J2入力支持橋へF685ZZ×2を反向きフランジで圧入し、40 mm入力軸と16Tを組む。印刷芯出し治具でサーボスプラインと入力軸を同軸化する。
7. 実測MG996Rホーンを純正中央ねじで装着し、実測穴のM3締結でホーンフランジを5 mm入力軸へ接続する。仮ホーンは使用しない。
8. 上腕右板一体32T、左右F695ZZ、102 mm固定肩軸を組み、ターンテーブル左右割締めをM3×17×2で固定する。上腕クロススペーサ2本を各端M3×9で締結する。
9. `GBN1353GT-90`を16T/32Tへ掛け、サーボ耳スロットと支持橋±1 mmスロットを同時調整する。無負荷手回しで歯底突当たり、片寄り、蛇行がない位置でM4×4と支持橋M3×4を締める。
10. J3 MG996Rを上腕一体座へM4×11×4で固定し、実測ホーン締結とF695/短軸/CL05Mで前腕を組む。
11. J4/J5 MG90Sを各一体座へM2×8×2で固定し、実MG90Sホーン、受動F695、J5 F685対、カラー、グリッパを組む。
12. 無通電1°走査、配線余長・抜け止め・工具アクセス確認後、電流制限付き低速、無負荷、50 g、30秒保持、120 deg/s²、600 deg/s²急停止の順に試験する。

締付トルクはクーポン破壊値の50%以下とする。サーボ耳は一体座へ全面着座させ、ケースとクレイドルの間には0.4 mm、可動部には0.5 mm以上の隙間を残す。

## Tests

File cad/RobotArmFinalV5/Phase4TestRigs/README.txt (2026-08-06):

Robot Arm V5 Phase 4 test rigs. Use eye protection, physical guards, a current-limited 6 V supply, and an NC emergency stop. Never hold the torque arm by hand during powered testing.

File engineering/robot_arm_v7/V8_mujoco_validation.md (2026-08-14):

# V8 MuJoCo検証

- 対象: `robot_arm_v8.xml`
- 現環境: `mujoco` Pythonモジュールなし。依存追加は行っていない。
- J2は実CADの `P-J2-BELT` のみを反映し、`q_servo=2q_J2`、`τ_J2=2×0.90×τ_servo`、最大1.6596 N·mとする。
- 16T、32T、ベルト、入力支持橋はMJCFへ形状を追加した。歯噛合いは低次元化された実伝達としてアクチュエータ倍率へ集約し、仮想の別動力源やFixed Jointは追加していない。
- J3は0.922 N·m、J4/J5は0.177 N·m、J1は実6:1遊星の効率込み0.690 N·m。

未実行の合格試験は、XMLコンパイル、J2/J3/J4/J5単軸1°走査、通常領域5°組合せ、折畳み経路1°補間、50 g重力保持、600 deg/s²停止である。実行結果がないため `AUD-MOTION-SWEEP-CURRENT` は意図的にFAILとし、過去形状の結果を流用しない。

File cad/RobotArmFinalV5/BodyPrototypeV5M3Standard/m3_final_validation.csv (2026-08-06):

part | policy | through_3_3_faces | insert_5x4_faces | head_5_2x1_faces | valid | solids
B01_BASE_LOWER | INSERT_POSITIVE | 8 | 8 | 0 | True | 1
B02_BASE_UPPER | HEAD_SIDE | 8 | 0 | 8 | True | 1
B03_J1_TURNTABLE | INSERT_POSITIVE | 8 | 8 | 0 | True | 1
B04_SHOULDER_YOKE_PLATE | HEAD_SIDE | 8 | 0 | 8 | True | 1
B05_UPPER_ARM_PLATE | HEAD_SIDE | 10 | 0 | 10 | True | 1
B06_FOREARM_PLATE | HEAD_SIDE | 10 | 0 | 10 | True | 1
B07_WRIST_PITCH_PLATE | HEAD_SIDE | 10 | 0 | 10 | True | 1
B08_J5_BEARING_CARRIER | INSERT_BOTH | 8 | 16 | 0 | True | 1
B09_M5_SPLIT_FLANGE_HUB | INSERT_POSITIVE | 6 | 1 | 0 | True | 1
B10_F695ZZ_RETAINER | HEAD_SIDE | 4 | 0 | 4 | True | 1
B11_LINK_SPACER_28 | INSERT_BOTH | 1 | 2 | 0 | True | 1
B12_YOKE_SPACER_38 | INSERT_BOTH | 1 | 2 | 0 | True | 1
B13_FIXED_GRIPPER_PALM | INSERT_POSITIVE | 8 | 8 | 0 | True | 1
B14_FIXED_GRIPPER_FINGER | HEAD_SIDE | 2 | 0 | 2 | True | 1
B16_J1_OUTPUT_GEAR_75T | HEAD_SIDE | 4 | 0 | 4 | True | 1
B18_J4_OUTPUT_GEAR_36T | HEAD_SIDE | 3 | 0 | 3 | True | 1
B19_MG90S_ADJUSTABLE_BASE | HEAD_SIDE | 0 | 0 | 0 | True | 1
B20_MG90S_SLIDING_JAW | INSERT_POSITIVE | 0 | 0 | 0 | True | 1
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

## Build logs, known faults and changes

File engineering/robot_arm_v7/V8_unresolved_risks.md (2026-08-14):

# V8 未解決リスクと完成判定

現在: `FAIL_NOT_COMPLETE / MG996R HORN, BELT COUPON, MOTION SWEEP, PHYSICAL TESTS PENDING`

| ID | 未解決事項 | 閉鎖条件 |
|---|---|---|
| R-01 | MG996R STEPにホーンがなく、J2/J3の実トルク接続が未完成 | 現物2個を独立測定し差≤0.10 mm、穴中心≤0.05 mmで `VERIFIED`、ホーンSTEPと締結を再生成 |
| R-02 | 印刷3GT歯形とGBN1353GT-90の容量・歯底隙間が未実証 | 同一条件クーポンで120.7 N以上、1000往復、歯飛び・亀裂・異常摩耗なし |
| R-03 | PA12-CF10インサート・軸受圧入の個体差 | M2/M3/M4引抜き・回転試験、F685/F695保持試験合格 |
| R-04 | J1 12T太陽歯の停止時歯元余裕が小さい | 電流制限、1000往復、定格慣性試験後に損傷なし |
| R-05 | MuJoCo 3.5環境がなく更新MJCFの全域走査未実行 | XMLコンパイル、各軸1°、通常領域5°組合せ、折畳み1°補間で禁止接触0 |
| R-06 | 配線包絡を剛体CADで完全表現していない | 実配線で全許可範囲100往復、擦れ・引張なし、動的隙間2 mm以上 |
| R-07 | 熱・急停止の実機確認未実施 | 4.8 V、50 g、30秒保持、120 deg/s²、600 deg/s²急停止を温度・電流記録付きで合格 |

J2は16T/32T、効率0.90で停止トルク1.6596 N·mとなり、最新CAD質量で急停止SF>1.5を満たす。一方、停止トルクは連続定格ではないため、数値合格だけでは製造承認しない。

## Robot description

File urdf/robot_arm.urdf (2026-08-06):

<?xml version="1.0"?>
<robot name="robotarm">
  <link name="base_link">
    <inertial>
      <mass value="0.06767"/>
      <inertia ixx="0.00006860" ixy="0" ixz="0" iyy="0.00006860" iyz="0" izz="0.00013648"/>
    </inertial>
    <visual>
      <geometry>
        <mesh filename="meshes/01_base_plate.stl" scale="0.001 0.001 0.001"/>
      </geometry>
      <material name="pla"><color rgba="0.75 0.78 0.82 1"/></material>
    </visual>
    <collision>
      <origin xyz="0 0 0" rpy="0 0 0"/>
      <geometry>
        <box size="0.1100 0.1100 0.0080"/>
      </geometry>
    </collision>
  </link>
  <link name="turret_link">
    <inertial>
      <mass value="0.04677"/>
      <inertia ixx="0.00002153" ixy="0" ixz="0" iyy="0.00002401" iyz="0" izz="0.00002196"/>
    </inertial>
    <visual>
      <geometry>
        <mesh filename="meshes/03_turret.stl" scale="0.001 0.001 0.001"/>
      </geometry>
      <material name="pla"><color rgba="0.75 0.78 0.82 1"/></material>
    </visual>
    <collision>
      <origin xyz="0 0 0" rpy="0 0 0"/>
      <geometry>
        <box size="0.0560 0.0500 0.0550"/>
      </geometry>
    </collision>
  </link>
  <link name="upper_link">
    <inertial>
      <mass value="0.02055"/>
      <inertia ixx="0.00000356" ixy="0" ixz="0" iyy="0.00002207" iyz="0" izz="0.00002294"/>
    </inertial>
    <visual>
      <geometry>
        <mesh filename="meshes/06_upper_arm_a.stl" scale="0.001 0.001 0.001"/>
      </geometry>
      <material name="pla"><color rgba="0.75 0.78 0.82 1"/></material>
    </visual>
    <collision>
      <origin xyz="0.0550 0 0" rpy="0 0 0"/>
      <geometry>
        <box size="0.1100 0.0360 0.0280"/>
      </geometry>
    </collision>
  </link>
  <link name="fore_link">
    <inertial>
      <mass value="0.01573"/>
      <inertia ixx="0.00000223" ixy="0" ixz="0" iyy="0.00001272" iyz="0" izz="0.00001317"/>
    </inertial>
    <visual>
      <geometry>
        <mesh filename="meshes/10_forearm_a.stl" scale="0.001 0.001 0.001"/>
      </geometry>
      <material name="pla"><color rgba="0.75 0.78 0.82 1"/></material>
    </visual>
    <collision>
      <origin xyz="0.0475 0 0" rpy="0 0 0"/>
      <geometry>
        <box size="0.0950 0.0320 0.0260"/>
      </geometry>
    </collision>
  </link>
  <link name="wrist_pitch_link">
    <inertial>
      <mass value="0.01017"/>
      <inertia ixx="0.00000125" ixy="0" ixz="0" iyy="0.00000212" iyz="0" izz="0.00000184"/>
    </inertial>
    <visual>
      <geometry>
        <mesh filename="meshes/12_wrist_pitch_yoke.stl" scale="0.001 0.001 0.001"/>
      </geometry>
      <material name="pla"><color rgba="0.75 0.78 0.82 1"/></material>
    </visual>
    <collision>
      <origin xyz="0.0200 0 0" rpy="0 0 0"/>
      <geometry>
        <box size="0.0400 0.0240 0.0300"/>
      </geometry>
    </collision>
  </link>
  <link name="wrist_roll_link">
    <inertial>
      <mass value="0.01000"/>
      <inertia ixx="0.00000131" ixy="0" ixz="0" iyy="0.00000199" iyz="0" izz="0.00000199"/>
    </inertial>
    <visual>
      <geometry>
        <mesh filename="meshes/13_wrist_roll_carrier.stl" scale="0.001 0.001 0.001"/>
      </geometry>
      <material name="pla"><color rgba="0.75 0.78 0.82 1"/></material>
    </visual>
    <collision>
      <origin xyz="0.0200 0 0" rpy="0 0 0"/>
      <geometry>
        <box size="0.0400 0.0280 0.0280"/>
      </geometry>
    </collision>
  </link>
  <link name="wrist_yaw_link">
    <inertial>
      <mass value="0.01000"/>
      <inertia ixx="0.00000053" ixy="0" ixz="0" iyy="0.00000053" iyz="0" izz="0.00000096"/>
    </inertial>
    <visual>
      <geometry>
        <mesh filename="meshes/14_wrist_yaw_flange.stl" scale="0.001 0.001 0.001"/>
      </geometry>
      <material name="pla"><color rgba="0.75 0.78 0.82 1"/></material>
    </visual>
    <collision>
      <origin xyz="0 0 0" rpy="0 0 0"/>
      <geometry>
        <box size="0.0240 0.0240 0.0080"/>
      </geometry>
    </collision>
  </link>
  <link name="gripper_link">
    <inertial>
      <mass value="0.02842"/>
      <inertia ixx="0.00000379" ixy="0" ixz="0" iyy="0.00000554" iyz="0" izz="0.00000660"/>
    </inertial>
    <visual>
      <geometry>
        <mesh filename="meshes/15_gripper_body.stl" scale="0.001 0.001 0.001"/>
      </geometry>
      <material name="pla"><color rgba="0.75 0.78 0.82 1"/></material>
    </visual>
    <collision>
      <origin xyz="0 0 0" rpy="0 0 0"/>
      <geometry>
        <box size="0.0420 0.0320 0.0240"/>
      </geometry>
    </collision>
  </link>
  <link name="camera_link">
    <inertial>
      <mass value="0.01000"/>
      <inertia ixx="0.00000042" ixy="0" ixz="0" iyy="0.00000308" iyz="0" izz="0.00000333"/>
    </inertial>
    <visual>
      <geometry>
        <mesh filename="meshes/19_camera_bracket.stl" scale="0.001 0.001 0.001"/>
      </geometry>
      <material name="pla"><color rgba="0.75 0.78 0.82 1"/></material>
    </visual>
    <collision>
      <origin xyz="0 0 0" rpy="0 0 0"/>
      <geometry>
        <box size="0.0600 0.0200 0.0100"/>
      </geometry>
    </collision>
  </link>
  <joint name="j1" type="revolute">
    <parent link="base_link"/>
    <child link="turret_link"/>
    <origin xyz="0.00000 0.00000 0.04800" rpy="0 0 0"/>
    <axis xyz="0 0 1"/>
    <limit lower="-1.57" upper="1.57" effort="20" velocity="2"/>
    <dynamics damping="0.08" friction="0.02"/>
  </joint>
  <joint name="j2" type="revolute">
    <parent link="turret_link"/>
    <child link="upper_link"/>
    <origin xyz="0.02200 0.00000 0.01000" rpy="0 0 0"/>
    <axis xyz="0 1 0"/>
    <limit lower="-1.2" upper="1.2" effort="20" velocity="2"/>
    <dynamics damping="0.08" friction="0.02"/>
  </joint>
  <joint name="j3" type="revolute">
    <parent link="upper_link"/>
    <child link="fore_link"/>
    <origin xyz="0.11000 0.00000 0.00000" rpy="0 0 0"/>
    <axis xyz="0 1 0"/>
    <limit lower="-1.4" upper="1.4" effort="5" velocity="2"/>
    <dynamics damping="0.08" friction="0.02"/>
  </joint>
  <joint name="j4" type="revolute">
    <parent link="fore_link"/>
    <child link="wrist_pitch_link"/>
    <origin xyz="0.09500 0.00000 0.00000" rpy="0 0 0"/>
    <axis xyz="0 1 0"/>
    <limit lower="-1.57" upper="1.57" effort="5" velocity="2"/>
    <dynamics damping="0.08" friction="0.02"/>
  </joint>
  <joint name="j5" type="revolute">
    <parent link="wrist_pitch_link"/>
    <child link="wrist_roll_link"/>
    <origin xyz="0.01833 0.00000 0.00000" rpy="0 0 0"/>
    <axis xyz="1 0 0"/>
    <limit lower="-1.57" upper="1.57" effort="5" velocity="2"/>
    <dynamics damping="0.08" friction="0.02"/>
  </joint>
  <joint name="j6" type="revolute">
    <parent link="wrist_roll_link"/>
    <child link="wrist_yaw_link"/>
    <origin xyz="0.01833 0.00000 0.00000" rpy="0 0 0"/>
    <axis xyz="0 0 1"/>
    <limit lower="-1.57" upper="1.57" effort="5" velocity="2"/>
    <dynamics damping="0.08" friction="0.02"/>
  </joint>
  <joint name="gripper" type="revolute">
    <parent link="wrist_yaw_link"/>
    <child link="gripper_link"/>
    <origin xyz="0.02000 0.00000 0.00000" rpy="0 0 0"/>
    <axis xyz="0 0 1"/>
    <limit lower="0.0" upper="0.7" effort="5" velocity="2"/>
    <dynamics damping="0.08" friction="0.02"/>
  </joint>
  <joint name="camera_tilt" type="revolute">
    <parent link="gripper_link"/>
    <child link="camera_link"/>
    <origin xyz="0.00000 0.00000 0.02800" rpy="0 0 0"/>
    <axis xyz="0 1 0"/>
    <limit lower="-0.8" upper="0.8" effort="5" velocity="2"/>
    <dynamics damping="0.08" friction="0.02"/>
  </joint>
</robot>

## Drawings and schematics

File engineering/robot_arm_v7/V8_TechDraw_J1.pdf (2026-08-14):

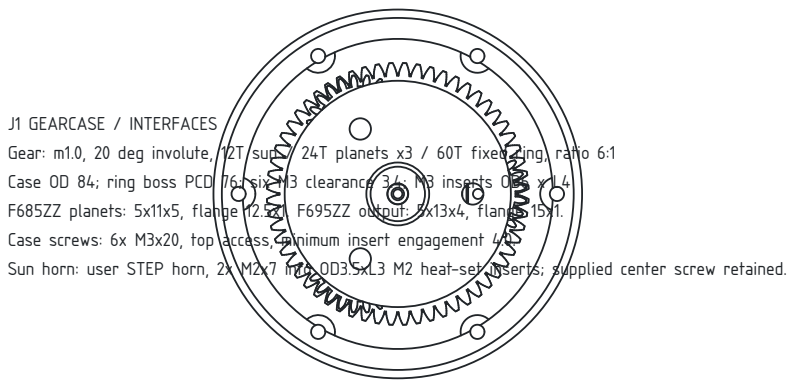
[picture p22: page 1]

J1 GEARCASE / INTERFACES
Gear: m1.0, 20 deg involute, 12T sun / 24T planets x3 / 60T fixed ring, ratio 6:1
Case OD 84; ring boss PCD 76; six M3 clearance 3.4; M3 inserts OD6 x L4
F685ZZ planets: 5x11x5, flange 12.5x1. F695ZZ output: 5x13x4, flange 15x1.

Case screws: 6x M3x20, top access, minimum insert engagement 4.0.

Sun horn: user STEP horn, 2x M2x7 into OD3.5xL3 M2 heat-set inserts; supplied center screw retained.

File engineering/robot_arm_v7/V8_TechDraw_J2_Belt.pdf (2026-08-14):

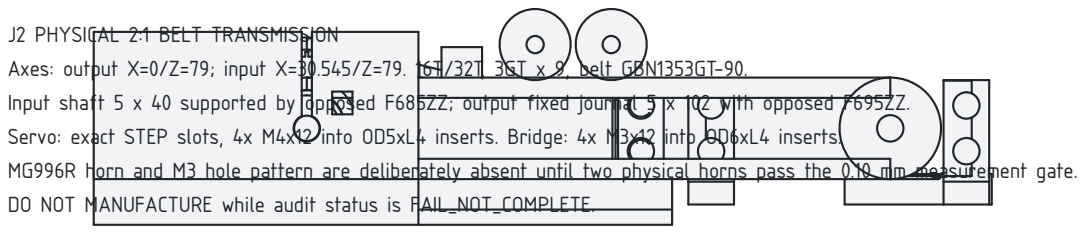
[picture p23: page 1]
Input shaft 5 x 40 supported by; opposed F685ZZ; output fixed journal 5; x 102 with opposed F695ZZ.; Servo: exact STEP slots, 4x M4x12 into OD5xL4 inserts. Bridge: 4x M3x12; into; OD6xL4 inserts. MG996R horn and M3 hole pattern are deliberately absent until two physical horns pass the 0.10 mm measurement gate.

J2 PHYSICAL 2:1 BELT TRANSMISSION
Axes: output X=0/Z=79; input X=30.545/Z=79. 16T/32T, 3GT x 9, belt GBN1353GT-90.

DO NOT MANUFACTURE while audit status is FAIL_NOT_COMPLETE.

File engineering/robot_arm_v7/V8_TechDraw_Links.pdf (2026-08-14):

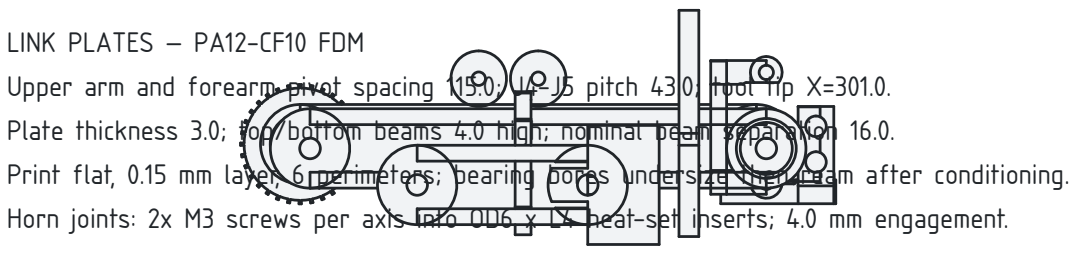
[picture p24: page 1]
Upper arm and forearm pivot spacing 115.0; J4-J5 pitch 43.0;; tool tip X=301.0.; Plate thickness 3.0; top/bottom beams 4.0 high; nominal beam; separation 16.0.; Print flat, 0.15 mm layer, 6; perimeters; bearing bores undersize then; ream after conditioning.; Horn joints: 2x M3 screws per axis; into OD6 x L4 heat-set; inserts; 4.0 mm engagement.

LINK PLATES — PA12-CF10 FDM

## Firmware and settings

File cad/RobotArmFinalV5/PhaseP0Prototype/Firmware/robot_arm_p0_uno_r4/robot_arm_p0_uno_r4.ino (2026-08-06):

/*
  Robot Arm V5.3-P0 — Arduino UNO R4 WiFi firmware

  Required library:
    ArduinoJson 7.x
    Servo (standard Arduino library)

  IMPORTANT:
  - The NC E-stop must physically cut servo power. This input is only status.
  - Safe NC circuits are wired to GND with INPUT_PULLUP, so LOW = safe/closed.
  - The servo-power-enable pin drives a suitable external MOSFET/relay circuit,
    never the servo rail directly.
*/

#include <ArduinoJson.h>
#include <Servo.h>

static const uint32_t BAUD = 115200;
static const uint32_t TELEMETRY_PERIOD_MS = 50;
static const uint32_t DEFAULT_WATCHDOG_MS = 200;

static const uint8_t SERVO_PINS[5] = {8, 9, 10, 11, 12};
static const uint8_t LIMIT_PINS[6] = {2, 3, 4, 5, 6, 7};
static const uint8_t SERVO_POWER_ENABLE_PIN = 13;
static const uint8_t ESTOP_STATUS_PIN = A2;
static const uint8_t CURRENT_SENSOR_PIN = A0;
static const uint8_t VOLTAGE_SENSOR_PIN = A1;

Servo servos[5];

// Replace after neutral calibration.
int neutralUs[5] = {1500, 1500, 1500, 1500, 1500};
int continuousSpanUs[5] = {200, 0, 0, 200, 200};
bool invertJoint[5] = {false, false, false, false, false};

int positionalMinUs[5] = {0, 700, 700, 0, 0};
int positionalMaxUs[5] = {0, 2300, 2300, 0, 0};

float commandSpeed[5] = {0, 0, 0, 0, 0};
float commandPositionDeg[5] = {0, 90, 90, 0, 0};
bool requestedEnable = false;
bool servoPowerEnabled = false;
uint32_t lastValidCommandMs = 0;
uint32_t watchdogMs = DEFAULT_WATCHDOG_MS;
uint32_t continuousWindowMs = 300;
uint32_t continuousMotionStartMs = 0;
bool continuousMotionActive = false;
uint32_t lastTelemetryMs = 0;
uint32_t lastSequence = 0;
String faultText = "";

uint16_t checksum16(const String &text) {
  uint32_t sum = 0;
  for (size_t i = 0; i < text.length(); ++i) {
    sum += static_cast<uint8_t>(text[i]);
  }
  return static_cast<uint16_t>(sum & 0xFFFF);
}

bool verifyChecksum(const String &line) {
  int marker = line.lastIndexOf(",\"check\":");
  if (marker < 0 || !line.endsWith("}")) return false;
  String base = line.substring(0, marker) + "}";
  JsonDocument doc;
  if (deserializeJson(doc, line)) return false;
  if (!doc["check"].is<int>()) return false;
  return static_cast<uint16_t>(doc["check"].as<int>()) == checksum16(base);
}

bool ncTriggered(uint8_t pin) {
  // LOW means the NC circuit is closed and safe.
  return digitalRead(pin) != LOW;
}

bool estopOpen() {
  return ncTriggered(ESTOP_STATUS_PIN);
}

float readServoVoltage() {
  // Placeholder calibration. Adjust dividerRatio and ADC reference by meter.
  const float adcReference = 5.0f;
  const float dividerRatio = 2.0f;
  float adc = analogRead(VOLTAGE_SENSOR_PIN);
  return adc * adcReference / 1023.0f * dividerRatio;
}

float readTotalCurrent() {
  // Placeholder for a centered analog current sensor. Calibrate before use.
  const float adcReference = 5.0f;
  const float zeroVoltage = 2.5f;
  const float voltsPerAmp = 0.185f;
  float voltage = analogRead(CURRENT_SENSOR_PIN) * adcReference / 1023.0f;
  return max(0.0f, (voltage - zeroVoltage) / voltsPerAmp);
}

void stopContinuousServos() {
  servos[0].writeMicroseconds(neutralUs[0]);
  servos[3].writeMicroseconds(neutralUs[3]);
  servos[4].writeMicroseconds(neutralUs[4]);
}

void disableServoPower(const String &reason) {
  requestedEnable = false;
  servoPowerEnabled = false;
  commandSpeed[0] = commandSpeed[3] = commandSpeed[4] = 0.0f;
  stopContinuousServos();
  digitalWrite(SERVO_POWER_ENABLE_PIN, LOW);
  if (reason.length() > 0) faultText = reason;
}

int speedToPulse(uint8_t joint, float speed) {
  speed = constrain(speed, -1.0f, 1.0f);
  if (invertJoint[joint]) speed = -speed;
  return neutralUs[joint] + static_cast<int>(
    round(speed * continuousSpanUs[joint])
  );
}

int degreesToPulse(uint8_t joint, float degrees) {
  degrees = constrain(degrees, 0.0f, 180.0f);
  if (invertJoint[joint]) degrees = 180.0f - degrees;
  float ratio = degrees / 180.0f;
  return static_cast<int>(
    round(positionalMinUs[joint] +
          ratio * (positionalMaxUs[joint] - positionalMinUs[joint]))
  );
}

void applyOutputs() {
  bool timedOut = millis() - lastValidCommandMs > watchdogMs;
  if (timedOut) {
    disableServoPower("command_watchdog");
    return;
  }
  if (estopOpen()) {
    disableServoPower("estop_open");
    return;
  }

  servoPowerEnabled = requestedEnable;
  digitalWrite(
    SERVO_POWER_ENABLE_PIN,
    servoPowerEnabled ? HIGH : LOW
  );

  if (!servoPowerEnabled) {
    stopContinuousServos();
    return;
  }

  // Continuous joints with direction-specific NC limit blocking.
  float j1 = commandSpeed[0];
  float j4 = commandSpeed[3];
  float j5 = commandSpeed[4];
  bool anyContinuous = abs(j1) > 0.0001f || abs(j4) > 0.0001f || abs(j5) > 0.0001f;
  if (anyContinuous && !continuousMotionActive) {
    continuousMotionActive = true;
    continuousMotionStartMs = millis();
  }
  if (!anyContinuous) {
    continuousMotionActive = false;
  }
  if (continuousMotionActive && millis() - continuousMotionStartMs >= continuousWindowMs) {
    j1 = j4 = j5 = 0.0f;
    commandSpeed[0] = commandSpeed[3] = commandSpeed[4] = 0.0f;
    continuousMotionActive = false;
  }
  if (j1 < 0 && ncTriggered(LIMIT_PINS[0])) j1 = 0;
  if (j1 > 0 && ncTriggered(LIMIT_PINS[1])) j1 = 0;
  if (j4 < 0 && ncTriggered(LIMIT_PINS[2])) j4 = 0;
  if (j4 > 0 && ncTriggered(LIMIT_PINS[3])) j4 = 0;
  if (j5 < 0 && ncTriggered(LIMIT_PINS[4])) j5 = 0;
  if (j5 > 0 && ncTriggered(LIMIT_PINS[5])) j5 = 0;

  servos[0].writeMicroseconds(speedToPulse(0, j1));
  servos[1].writeMicroseconds(
    degreesToPulse(1, commandPositionDeg[1])
  );
  servos[2].writeMicroseconds(
    degreesToPulse(2, commandPositionDeg[2])
  );
  servos[3].writeMicroseconds(speedToPulse(3, j4));
  servos[4].writeMicroseconds(speedToPulse(4, j5));
}

void sendTelemetry() {
  JsonDocument doc;
  doc["type"] = "telemetry";
  doc["seq"] = lastSequence;
  doc["enabled"] = servoPowerEnabled;
  JsonArray limits = doc["limits"].to<JsonArray>();
  for (uint8_t i = 0; i < 6; ++i) {
    limits.add(ncTriggered(LIMIT_PINS[i]) ? 1 : 0);
  }
  doc["voltage"] = readServoVoltage();
  doc["current"] = readTotalCurrent();
  doc["estop_open"] = estopOpen();
  if (faultText.length() > 0) {
    doc["fault"] = faultText;
  } else {
    doc["fault"] = nullptr;
  }

  String base;
  serializeJson(doc, base);
  uint16_t check = checksum16(base);
  String framed = base.substring(0, base.length() - 1);
  framed += ",\"check\":";
  framed += String(check);
  framed += "}\n";
  Serial.print(framed);
}

void handleCommand(const JsonDocument &doc) {
  lastSequence = doc["seq"] | lastSequence;
  requestedEnable = doc["enable"] | false;
  commandSpeed[0] = constrain(
    doc["j1_speed"] | 0.0f, -0.25f, 0.25f
  );
  commandPositionDeg[1] = constrain(
    doc["j2_deg"] | 90.0f, 30.0f, 145.0f
  );
  commandPositionDeg[2] = constrain(
    doc["j3_deg"] | 90.0f, 25.0f, 150.0f
  );
  commandSpeed[3] = constrain(
    doc["j4_speed"] | 0.0f, -0.25f, 0.25f
  );
  commandSpeed[4] = constrain(
    doc["j5_speed"] | 0.0f, -0.25f, 0.25f
  );
  watchdogMs = constrain(
    doc["timeout_ms"] | DEFAULT_WATCHDOG_MS,
    100UL,
    1000UL
  );
  continuousWindowMs = constrain(
    doc["continuous_window_ms"] | 300UL,
    100UL,
    1000UL
  );
  faultText = "";
  lastValidCommandMs = millis();
}

void handleNeutralCalibration(const JsonDocument &doc) {
  const char *jointName = doc["joint"] | "";
  int joint = -1;
  if (strcmp(jointName, "J1") == 0) joint = 0;
  if (strcmp(jointName, "J4") == 0) joint = 3;
  if (strcmp(jointName, "J5") == 0) joint = 4;
  if (joint < 0) return;

  int pulse = constrain(doc["pulse_us"] | 1500, 1300, 1700);
  neutralUs[joint] = pulse;
  requestedEnable = doc["enable"] | false;
  lastSequence = doc["seq"] | lastSequence;
  lastValidCommandMs = millis();
  if (requestedEnable && !estopOpen()) {
    digitalWrite(SERVO_POWER_ENABLE_PIN, HIGH);
    servoPowerEnabled = true;
    servos[joint].writeMicroseconds(pulse);
  }
}

void processLine(const String &line) {
  if (!verifyChecksum(line)) {
    disableServoPower("invalid_checksum");
    return;
  }
  JsonDocument doc;
  DeserializationError error = deserializeJson(doc, line);
  if (error) {
    disableServoPower("invalid_json");
    return;
  }
  const char *type = doc["type"] | "";
  if (strcmp(type, "command") == 0) {
    handleCommand(doc);
  } else if (strcmp(type, "calibrate_neutral") == 0) {
    handleNeutralCalibration(doc);
  } else {
    disableServoPower("unknown_message");
  }
}

void setup() {
  Serial.begin(BAUD);
  analogReadResolution(10);
  pinMode(SERVO_POWER_ENABLE_PIN, OUTPUT);
  digitalWrite(SERVO_POWER_ENABLE_PIN, LOW);
  pinMode(ESTOP_STATUS_PIN, INPUT_PULLUP);
  for (uint8_t i = 0; i < 6; ++i) {
    pinMode(LIMIT_PINS[i], INPUT_PULLUP);
  }
  for (uint8_t i = 0; i < 5; ++i) {
    servos[i].attach(SERVO_PINS[i]);
  }
  stopContinuousServos();
  servos[1].writeMicroseconds(degreesToPulse(1, 90));
  servos[2].writeMicroseconds(degreesToPulse(2, 90));
  lastValidCommandMs = millis();
}

void loop() {
  static String line;
  while (Serial.available()) {
    char c = static_cast<char>(Serial.read());
    if (c == '\n') {
      line.trim();
      if (line.length() > 0) processLine(line);
      line = "";
    } else if (c != '\r') {
      if (line.length() < 512) {
        line += c;
      } else {
        line = "";
        disableServoPower("line_too_long");
      }
    }
  }

  applyOutputs();

  if (millis() - lastTelemetryMs >= TELEMETRY_PERIOD_MS) {
    lastTelemetryMs = millis();
    sendTelemetry();
  }
}

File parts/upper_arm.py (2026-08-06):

"""Compact dual-plate upper arm with internal elbow MG90S cradle at distal end."""

from __future__ import annotations

import Part

import params as P
from cad.sketch_pad import cut, cyl, fuse, pad_xy, rotate, translate
from parts.joint_features import bearing_seat, insert_m3, servo_body_pocket, shaft_clearance, soft_stop_pad, tab_holes


def _plate(length: float, height: float) -> Part.Shape:
    return pad_xy([(0, 0), (length, 0), (length, height), (0, height)], P.PLATE_T)


def _split(length, male, female):
    adds, cuts = [], []
    sp = P.SPLIT_BOLT_SPACING
    corners = [(-sp / 2, -sp / 2), (sp / 2, -sp / 2), (-sp / 2, sp / 2), (sp / 2, sp / 2)]
    # through cable in mid plane
    cuts.append(cyl(P.CABLE_HOLE_D / 2, length + 2, (-1, 0, 0), "x"))
    if male:
        for py, pz in corners:
            adds.append(cyl(P.DOWEL_D / 2 - 0.1, 4.5, (length, py, pz), "x"))
            cuts.append(cyl(P.M3["clear_d"] / 2, 20, (length - 16, py, pz), "x"))
            cuts.append(cyl(P.M3["head_d"] / 2, P.M3["head_h"] + 0.3, (length - 3, py, pz), "x"))
    if female:
        for py, pz in corners:
            cuts.append(cyl(P.DOWEL_D / 2 + 0.15, 5, (-0.4, py, pz), "x"))
            cuts.append(insert_m3((-0.2, py, pz), "x"))
    return adds, cuts


def make_upper_arm_a() -> Part.Shape:
    """Proximal dual plates + spacers (assembled as one printable pair fused for export simplicity)."""
    L = P.UPPER_SEG_A
    h = P.LINK_HEIGHT
    yi = P.LINK_INNER / 2
    left = translate(_plate(L, h), 0, -yi - P.PLATE_T, -h / 2)
    right = translate(_plate(L, h), 0, yi, -h / 2)
    # rotate plates: currently extruded in Z from XY — need plates in XZ with thickness Y
    # Rebuild: plate as pad in XZ via pad_xy on X-length × Z-height then... use box-like pad along Y
    left = pad_xy([(0, -yi - P.PLATE_T), (L, -yi - P.PLATE_T), (L, -yi), (0, -yi)], h, z0=-h / 2)
    right = pad_xy([(0, yi), (L, yi), (L, yi + P.PLATE_T), (0, yi + P.PLATE_T)], h, z0=-h / 2)
    sp_a = pad_xy([(8, -yi), (18, -yi), (18, yi), (8, yi)], 4, z0=-2)
    sp_b = pad_xy([(L - 22, -yi), (L - 12, -yi), (L - 12, yi), (L - 22, yi)], 4, z0=-2)
    body = fuse([left, right, sp_a, sp_b])
    adds, cuts = _split(L, True, False)
    for y in (-yi - P.PLATE_T / 2, yi + P.PLATE_T / 2):
        for z in (-6, 6):
            cuts.append(cyl(P.M3["clear_d"] / 2, 14, (-1, y, z), "x"))
    body = fuse([body] + adds) if adds else body
    return cut(body, cuts)


def make_upper_arm_b() -> Part.Shape:
    L = P.UPPER_SEG_B
    h = P.LINK_HEIGHT
    yi = P.LINK_INNER / 2
    left = pad_xy([(0, -yi - P.PLATE_T), (L, -yi - P.PLATE_T), (L, -yi), (0, -yi)], h, z0=-h / 2)
    right = pad_xy([(0, yi), (L, yi), (L, yi + P.PLATE_T), (0, yi + P.PLATE_T)], h, z0=-h / 2)
    sp = pad_xy([(10, -yi), (20, -yi), (20, yi), (10, yi)], 4, z0=-2)
    body = fuse([left, right, sp])
    adds, cuts = _split(L, False, True)
    p = P.MG90S
    # Distal internal cradle block spanning inner width
    cl = p["tab_l"] + 6
    cw = P.LINK_INNER
    ch = p["body_h_total"] + 4
    cradle = pad_xy([(L - 4, -cw / 2), (L - 4 + cl, -cw / 2), (L - 4 + cl, cw / 2), (L - 4, cw / 2)], ch, z0=-ch / 2)
    body = fuse([body] + adds + [cradle])
    cx = L - 4 + cl / 2
    cuts += [translate(servo_body_pocket(p), cx, 0, 0), tab_holes(p, ch / 2 - 1)]
    bp = translate(rotate(bearing_seat(P.F695ZZ, "+z"), (1, 0, 0), 90), cx, -cw / 2, 0)
    shaft = shaft_clearance(cw + 6, (cx, -cw / 2 - 3, 0), "y")
    stop = translate(soft_stop_pad(5, 3), cx + 8, cw / 2 + 0.5, -ch / 2)
    body = fuse([body, stop])
    cuts += [bp, shaft]
    return cut(body, cuts)


def make_all():
    return {"06_upper_arm_a": make_upper_arm_a(), "07_upper_arm_b": make_upper_arm_b()}
